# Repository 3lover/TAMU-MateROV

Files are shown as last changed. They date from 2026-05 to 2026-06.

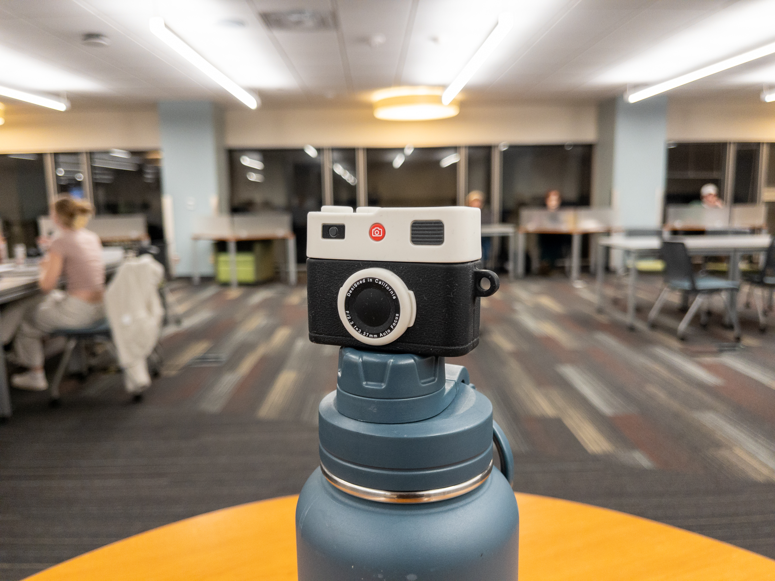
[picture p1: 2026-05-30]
25-26/01_Subteams/GNC/Photogrammetry Test Files/APC_0051.jpg

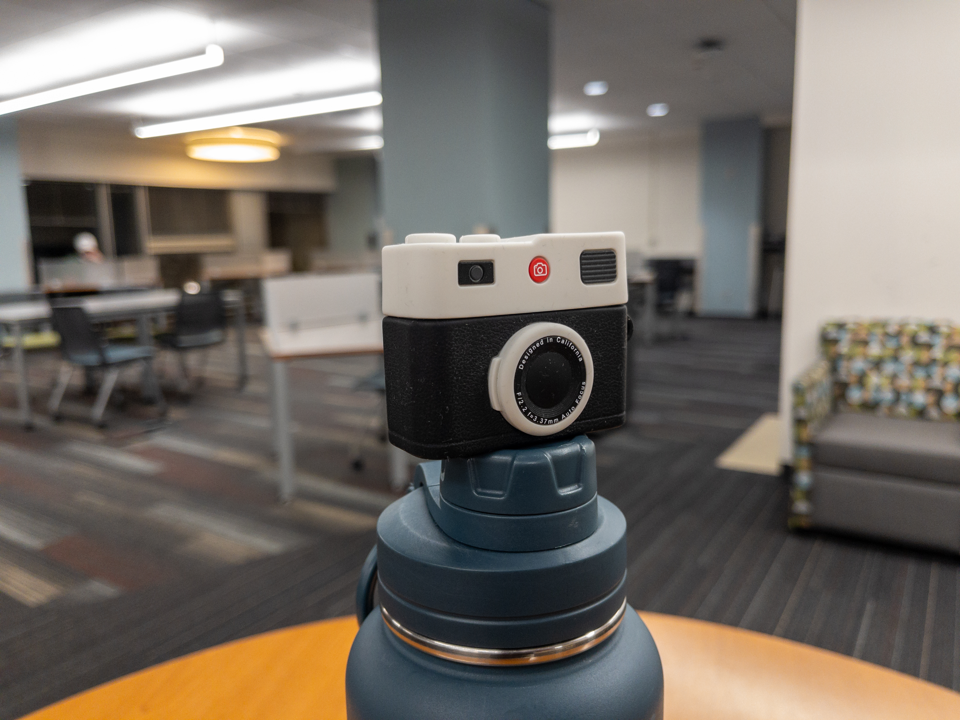
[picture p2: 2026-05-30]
25-26/01_Subteams/GNC/Photogrammetry Test Files/APC_0047.jpg

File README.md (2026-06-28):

# Team Oceanus — MATE ROV 🌊

Texas A&M underwater robotics team (ThinkTank) building an ROV and float for the
[MATE ROV Competition](https://materovcompetition.org/). This is our team
monorepo — design, code, and documentation, organized by subteam.

## The ROV at a glance

- **8-thruster, fully 6-DoF frame** — vectored (ArduSub `vectored_6dof`), with independent roll & pitch
- **Diamond Dynamics TD1.2** thrusters (4 horizontal + 4 vertical)
- **Navigator** flight controller on a **Raspberry Pi 5**, running **BlueOS + ArduSub**
- Piloted over **MAVLink** in QGroundControl; a companion **float** (vertical profiler) runs its own firmware

## Subteams

| Subteam | Focus |
|---|---|
| **GNC** — Guidance, Navigation & Control | Control software, ArduSub SITL simulation, photogrammetry |
| **EPS** — Electrical Power Supply | Power distribution, PCB design |
| **TMS** — Thermal Mechanisms & Structures | Chassis, frame, claw, and float CAD |
| **C&C** — Communication & Computing | ROV & float code, software architecture |
| **F&P** — Fluids & Propulsion | Propellers, fluid/structural analysis (CFD/FEA) |

Each subteam's plans and notes live under [`01_Subteams/`](01_Subteams/).

> **Note:** C&C and GNC are planned to merge into a single subteam.

## Repository layout

| Path | Contents |
|---|---|
| [`01_Subteams/`](01_Subteams/) | Active work, by subteam (**canonical**) |
| [`FloatCode/`](FloatCode/) | Float (vertical profiler) firmware |
| [`ROV CAD files/`](ROV%20CAD%20files/) | Mechanical CAD |
| [`WiringSchematics/`](WiringSchematics/) | Electrical wiring diagrams |
| [`Technical Data/`](Technical%20Data/) | Datasheets and specs |
| [`doc/`](doc/) | Documentation |
| `25-26/` | Previous-season archive (not active) |

## Software highlights

- **GNC SITL simulation** — full ArduSub 6-DoF sim of our ROV, for testing control before hardware: [`01_Subteams/GNC/SITL-Simulation`](01_Subteams/GNC/SITL-Simulation)
- **Photogrammetry Studio** — RTSP-to-3D scanning app (macOS): [latest release](https://github.com/akvaithi/MATE-ROV-Photogrammetry/releases/latest)

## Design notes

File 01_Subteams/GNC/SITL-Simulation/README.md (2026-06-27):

# GNC SITL Simulation — ArduSub 6-DoF

Software-In-The-Loop (SITL) environment for validating Team Oceanus' control
systems and **custom 6-DoF frame configuration** before they touch hardware.

This runs the **real ArduSub firmware** against a simulated vehicle, so the same
frame mixing, PID loops, depth/heading hold, and MAVLink commands you test here
behave identically on the **Navigator + Raspberry Pi 5 + BlueOS** stack
(per `GNC-ICD-01`). That's why SITL is the right tool — not a hand-rolled
physics sim, which wouldn't match the autopilot.

> Covers **Goal 1 (Configure & Simulate 6-DoF Vehicle)** and **Practice Project 2
> (MAVLink heartbeat + IMU read)**, and gives the servo/thruster work
> (**Goal 2**) a place to run before hardware is ready.

---

## Status: validated end-to-end ✅

Built and run on macOS (Apple Silicon) with **ArduSub V4.5.7**. The sim boots
into `Frame: VECTORED_6DOF`, telemetry streams, and all six degrees of freedom
exercise the expected thrusters:

| Command | horizontal 1-4 | vertical 5-8 |
|---|---|---|
| neutral | 1500 1500 1500 1500 | 1500 1500 1500 1500 |
| forward | 1250 1250 1750 1750 | 1500 1500 1500 1500 |
| lateral | 1750 1250 1750 1250 | 1500 1500 1500 1500 |
| heave | 1500 1500 1500 1500 | 1250 1250 1250 1250 |
| yaw | 1750 1250 1250 1750 | 1500 1500 1500 1500 |
| roll | 1500 1500 1500 1500 | 1750 1250 1750 1250 |
| pitch | 1500 1500 1500 1500 | 1250 1250 1750 1750 |

Independent **roll and pitch** (driven by the 4 vertical thrusters) confirm true
6-DoF — a 2-vertical-thruster frame could not do this.

---

## The 6-DoF decision (why `vectored_6dof`)

| Frame | Thrusters | Controllable DoF | ArduSub `FRAME_CONFIG` |
|---|---|---|---|
| `vectored` (BlueROV2) | 6 (4 vec + 2 vert) | 4 — surge, sway, heave, yaw | 1 |
| **`vectored_6dof` (BlueROV2 Heavy)** | **8 (4 vec + 4 vert)** | **6 — adds roll & pitch** | **2** |

True, independently-controllable 6-DoF needs the **4 vertical thrusters** — with
only 2 vertical thrusters you cannot actively control roll and pitch. The
**8-thruster `vectored_6dof`** frame is the team's **final design** (confirmed
June 2026; BOM = 4 CW + 4 CCW T200s, ICD wiring T1–T8). See
[../Frame-Config-Decision.md](../Frame-Config-Decision.md).

---

## Prerequisites

- **Docker Desktop** (macOS/Windows/Linux). This is the clean path on macOS,
  where native ArduPilot builds are painful.
- **QGroundControl** (for visual flight + PID tuning) — optional but recommended.
- **Python 3.10+** on your host for the scripts (`pip install -r scripts/requirements.txt`).

## Quick start

```bash
cd "01_Subteams/GNC/SITL-Simulation"
./run_sitl.sh            # first run builds the image (~20-40 min, ~6 GB), then launches
```

When it prints the MAVProxy banner, the sim is live:

| Connect | Endpoint | For |
|---|---|---|
| GNC scripts / pymavlink | `tcp:127.0.0.1:5780` | telemetry + commands |
| QGroundControl | `tcp:localhost:5781` | add **Application Settings → Comm Links → Add → TCP**, host `localhost`, port `5781` |

Then, in another terminal:

```bash
cd "01_Subteams/GNC/SITL-Simulation"
python3 -m venv .venv && source .venv/bin/activate
pip install -r scripts/requirements.txt

python3 scripts/sitl_check.py        # Project 2: heartbeat + live IMU / attitude / depth
python3 scripts/thruster_mixing.py   # drive each DoF, confirm 8-thruster frame mixing
```

Stop the sim with `Ctrl-C` in the `run_sitl.sh` terminal.

## Capturing & presenting results

No 3D viewer needed — record a run and turn it into one shareable figure:

```bash
# 1. start logging in one terminal (depth, attitude, position, power, thrusters)
python3 scripts/log_telemetry.py tcp:127.0.0.1:5780 run1.csv 10
# 2. fly the ROV (QGC joysticks, or thruster_mixing.py) — Ctrl-C the logger when done
# 3. render a dashboard PNG for the test report / presentation
python3 scripts/plot_telemetry.py run1.csv run1.png "Dive + Forward Test"
```

The dashboard shows the path travelled, depth profile, attitude, which thrusters
fired when, power draw, and speed — so testing reads as a picture, not numbers.

## Water-current testing (ConOps current compensation)

Stock ArduSub SITL is still water, so we patch the model (`apply_current_model.sh`,
baked into the image) so `SIM_WIND_SPD`/`SIM_WIND_DIR` act as a horizontal
**water current**. Set it live — no rebuild:

```bash
python3 scripts/inject_current.py 0.4 90   # 0.4 m/s toward east (090)
python3 scripts/inject_current.py 0        # back to still water
python3 scripts/inject_current.py demo     # drift at 0 / 0.5 / 1.0 m/s
```

Unpowered, the ROV drifts toward the current at the current speed — so you can
test drift detection and station-keeping / current-compensation control. See the
`current-drift_*` example in [sample-runs/](sample-runs/).

**Current compensation** — `station_keeping.py` is a PID position-hold (NED error
→ forward/lateral thrust, depth held by the autopilot) that cancels the drift:

```bash
python3 scripts/inject_current.py 0.4 90    # add a 0.4 m/s current
python3 scripts/station_keeping.py          # hold position against it
```

Tuned gains (Kp=440, Kd=230, Ki=210) hold to ~**0.01 m** steady-state against a
constant 0.4 m/s current (the integral term removes the proportional droop), and
**mean ~0.12 m** against a *random* current that changes every few seconds. See
the `current-compensation_*` and `variable-current_*` samples in
[sample-runs/](sample-runs/).

## Servo control architecture (Goal 2)

The manipulator servos are on PWM channels **14-16** (GNC-ICD-01). They default to
`SERVOn_FUNCTION = 0` (Disabled), which lets the GCS drive them directly with
`MAV_CMD_DO_SET_SERVO` — no reboot or reconfig:

```bash
python3 scripts/servo_control.py gripper open       # ch14 -> 1900
python3 scripts/servo_control.py 14 deg 90          # angle command
python3 scripts/servo_control.py 15 sweep           # exercise a channel
python3 scripts/servo_test.py tcp:127.0.0.1:5780 14 40   # latency + precision -> report
```

`servo_test.py` produces the **Goal 2 test report** (`sample-runs/servo-control_report.md`):
command-path latency **~10 ms** (mean) and **0 µs** command error in SITL.

> SITL models the command/firmware path, not mechanical servo travel or physical
> positional error — measure those on the bench and add to the latency above.

---

## What's in here

| File | Purpose |
|---|---|
| `Dockerfile` | Builds ArduSub SITL from source (firmware = ground truth) |
| `sim_entry.sh` | Container entrypoint: starts SITL + a MAVProxy hub (multi-client) |
| `docker-compose.yml` / `run_sitl.sh` | One-command build & launch |
| `apply_oceanus_model.sh` + [`OCEANUS-VEHICLE-MODEL.md`](OCEANUS-VEHICLE-MODEL.md) | Patches SITL physics to our ROV's mass/size/thrust (edit + rebuild to update) |
| `params/vectored_6dof.parm` | The custom-frame parameter set (also `param load`-able onto the real Navigator) |
| `scripts/sitl_check.py` | Project 2 — heartbeat + IMU/attitude/depth stream |
| `scripts/thruster_mixing.py` | Drive each DoF via RC override, read SERVO_OUTPUT_RAW |
| `scripts/log_telemetry.py` | Record depth/attitude/position/battery/thrusters to CSV for reports |
| `scripts/plot_telemetry.py` | Turn a logged CSV into a shareable dashboard PNG (no 3D sim needed) |
| `scripts/inject_current.py` | Add a water current (ConOps drift / current-compensation testing) |
| `scripts/station_keeping.py` | PID position-hold that counters the current (ConOps current compensation) |
| `scripts/servo_control.py` | Drive the manipulator servos (ch 14-16) via MAV_CMD_DO_SET_SERVO |
| `scripts/servo_test.py` | Servo latency + precision test → CSV, chart, report (Goal 2) |
| `apply_current_model.sh` | Build-time patch making SIM_WIND act as a water current |

---

## Custom ArduSub frame config — step by step (deliverable)

1. **Pick the frame.** 8-thruster Heavy geometry → `FRAME_CONFIG = 2` (`vectored_6dof`).
   In SITL this is selected by `sim_vehicle.py -f vectored_6dof` (already wired in `sim_entry.sh`).
2. **On hardware**, set the same in QGroundControl → **Vehicle Setup → Frame**, or
   load `params/vectored_6dof.parm` via **Parameters → Tools → Load from file**.
3. **Confirm the mixing** with `scripts/thruster_mixing.py`: each DoF should move
   the expected group of thrusters (horizontals for surge/sway/yaw, verticals for
   heave/roll/pitch). Cross-check against `GNC-ICD-01 Figure 4 (Thruster
   Configuration)` and the
   [ArduSub thruster setup guide](https://www.ardusub.com/quick-start/vehicle-frame.html).
   (Note: ArduSub's `MAV_CMD_DO_MOTOR_TEST` is unreliable in SITL — it times out —
   so we exercise the mix via RC override instead.)
4. **Tune** depth-hold / heading-hold (`PSC_POSZ_P`, `ATC_ANG_YAW_P`) in QGC
   against SITL, then carry the values to the Navigator.
5. **Non-standard geometry?** If the thruster angles/positions differ from
   BlueROV2 Heavy, a fully custom motor matrix means editing
   `AP_Motors6DOF::setup_motors()` and rebuilding (bump `FRAME_CONFIG` to its
   Custom slot). Open an issue and we'll branch the Dockerfile for it.

---

## Troubleshooting

- **Build fails on `install-prereqs`** — usually a transient apt mirror issue;
  re-run `./run_sitl.sh`. The build layer is cached up to that point.
- **`FRAME_CONFIG` not 2 after boot** — connect with QGC or MAVProxy and
  `param set FRAME_CONFIG 2`, then reboot the sim. Report it so we can pin the param file.
- **Scripts can't connect** — make sure `run_sitl.sh` printed the MAVProxy banner
  and ports 5780/5781 aren't taken (`lsof -i :5780`).
- **Different ArduSub version** — rebuild with another release:
  `docker compose build --build-arg ARDUSUB_REF=Sub-4.1`.

## References

- ArduSub SITL setup — https://www.ardusub.com/developers/sitl.html
- ArduSub frames / thrusters — https://www.ardusub.com/quick-start/vehicle-frame.html
- pymavlink + ArduSub examples — https://www.ardusub.com/developers/pymavlink.html
- MAVProxy — https://ardupilot.org/mavproxy/

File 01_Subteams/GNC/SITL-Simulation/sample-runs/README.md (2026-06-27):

# Sample SITL runs

Example telemetry from the same scripted maneuver (settle → dive → cruise → turn
→ forward → strafe → surface), captured with `scripts/log_telemetry.py` and
rendered with `scripts/plot_telemetry.py`.

| Run | Vehicle model | Dive (same command) |
|---|---|---|
| `bluerov2-baseline_*` | ArduPilot stock BlueROV2 (10.5 kg, T200-class 51.5 N) | ~5.8 m |
| `oceanus-td12_*` | Team Oceanus model: 22 kg + **Diamond Dynamics TD1.2** thrusters (24.5 N) — see [../OCEANUS-VEHICLE-MODEL.md](../OCEANUS-VEHICLE-MODEL.md) | ~3.5 m |
| `current-drift_*` | Oceanus model holding depth while a **0.6 m/s current** is switched on — drifts ~14 m east (ConOps current-compensation test) | n/a |
| `current-compensation_*` | `station_keeping.py` PID vs a **0.4 m/s current**: drifts ~3.9 m during a no-control phase, then recovers to within ~0.2 m and holds | n/a |
| `variable-current_*` | `station_keeping.py` (tuned) vs a **random current** that changes every ~3–4 s (13 changes): holds **mean 0.12 m / max 0.31 m**. `_response.png` overlays the disturbance and the position error | n/a |
| `servo-control*` | **Goal 2** servo test on ch 14: command-path latency ~10 ms mean, 0 µs precision error. `_report.md` is the test report, `.png` the latency/precision chart, `.csv` the raw data | n/a |

Same command, shallower dive: the Oceanus ROV is heavier **and** its TD1.2 thrusters
push less than half a T200, so it's a slower, gentler vehicle. Top speed in the
Oceanus run is ~0.7 m/s vs ~1.2 m/s on the baseline.

Each run has a `_dashboard.png` (shareable figure) and a `_telemetry.csv` (raw log).
The Oceanus model still uses **design-target/estimated** mass and dimensions
(only the thrusters are a confirmed real value) — regenerate once the ROV is weighed.

To make your own: see "Capturing & presenting results" in the [main README](../README.md).

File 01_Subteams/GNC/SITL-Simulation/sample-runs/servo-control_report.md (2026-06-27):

# Servo Control Architecture — Test Report

**Channel:** 14 (manipulator, per GNC-ICD-01)  ·  **Iterations:** 40  ·  **Env:** ArduSub SITL

## Response latency (MAV_CMD_DO_SET_SERVO → output register)
| metric | value |
|---|---|
| mean | 10.0 ms |
| p95  | 18.0 ms |
| max  | 27.8 ms |

Measured at 200 Hz SERVO_OUTPUT_RAW (±5 ms quantisation). This is the
MAVLink + firmware command latency, not mechanical servo travel.

## Command precision (commanded vs actual PWM)
| metric | value |
|---|---|
| max error | 0 µs |
| range tested | 1100–1900 µs |

The command path is exact in SITL (pass-through), so precision here validates
PWM resolution, not mechanical positioning.

## On hardware (to be measured on the bench)
- Mechanical travel time per degree (add to the latency above).
- Physical positional accuracy / repeatability of the servo.
- Holding torque under load.

Artifacts: `servo-control.csv`, `servo-control.png`

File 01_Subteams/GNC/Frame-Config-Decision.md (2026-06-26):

# Frame Config — Decision Record

**Decision:** The ROV uses **8 thrusters** in a **vectored 6-DoF** layout
(BlueROV2 "Heavy" style). In ArduSub this is **`FRAME_CONFIG = 2`
(`vectored_6dof`)**. *Final as of June 2026.*

## Why / evidence
| Source | Evidence |
|---|---|
| GNC-ICD-01, Fig. 4 (wiring) | T1–T8 → ESC 1–8 → PWM channels 1–8; 3 servos on channels 14–16 |
| Thrusters | 4 CW + 4 CCW **Diamond Dynamics TD1.2** = 8 (torque-balanced pairs; ~2.5 kgf max each) |
| CAD | `Horizontal Mount` + `Vertical Mount` parts; `Thruster Configuration Assembly.SLDASM` |
| Hardware | Navigator flight controller + Pi 5 + BlueOS + ArduSub |

8 thrusters give true 6-DoF: 4 horizontal (surge / sway / yaw) + 4 vertical
(heave / **roll / pitch**). A 6-thruster frame (2 vertical) could not control
roll and pitch — that's why 8 is required.

## Resolved conflict
Earlier design docs disagreed on count:
- `F&P/.../Thrusters - Number...` leaned toward **4** thrusters (no pitch).
- `Research Notes/GNC/ROV Software & Hardware Architecture...` cited a **4**-thruster baseline.
- BOM + ICD wiring specify **8**.

**8 is final.** The blank "6 positions" in the spec-sheet *template* is just an
unfilled template, not the design.

## Still to verify in CAD (does not affect the sim)
`vectored_6dof` assumes the 4 horizontal thrusters are mounted **~45° in the
corners**. Confirm in `Thruster Configuration Assembly.SLDASM` (top-down):
- Horizontals **45°-vectored** → `vectored_6dof` is exact, no extra work.
- Horizontals **straight** → custom motor matrix needed (recompile ArduSub).

Validated in SITL — see [SITL-Simulation/](SITL-Simulation/).

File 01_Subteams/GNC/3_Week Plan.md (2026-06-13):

# GNC Project Plan

## Objective

Finalize GNC software configurations, validate remaining control systems in simulation, validate servo control architecture, and refine the photogrammetry pipeline for future hardware integration.

---

## Goals Overview

| Goal | Measurables | Deliverables |
|---|---|---|
| **Configure & simulate 6-DoF vehicle** | Successful loading of custom 6-DoF frame config into ArduSub/BlueOS; successful execution of control algorithms in SITL | Custom frame configuration file; validated simulation environment; updated control architecture documentation |
| **Validate servo control architecture** | Successful actuation of test servos via BlueOS/MAVLink; minimal latency and precise positional control achieved | Code repository with servo control scripts; test report documenting response times and precision metrics |
| **Refine photogrammetry pipeline** | Continuous processing of RTSP video stream into 3D models with minimal error and dropped frames | Updated Python application code; documentation of RTSP-to-3D pipeline and performance metrics |

---

## Software & Tools

| Software/Tool | Purpose | Members | Resources/Links |
|---|---|---|---|
| BlueOS | Core ROV operating system and communication | All GNC members | [BlueOS Documentation](https://docs.bluerobotics.com/ardusub-zola/software/onboard/BlueOS/) |
| Python | Custom application development (photogrammetry, control scripts) | All GNC members | [Python.org](https://www.python.org) |
| MAVLink / pymavlink | Communication protocol between GNC software and hardware | All GNC members | [MAVLink Developer Guide](https://mavlink.io/en/) |
| ArduSub (SITL) | Software-in-the-loop simulation for testing control algorithms and custom frame configurations | All GNC members | [ArduSub SITL Guide](https://ardusub.com/developers/sitl.html) |
| GitHub | Version control and task management | All GNC members | [TAMU-MateROV Repo](https://github.com/3lover/TAMU-MateROV) |

---

## Training Plan

**Custom frame configuration in ArduSub**
- Review ArduSub documentation on creating and compiling custom motor matrices for non-standard frame geometries

**BlueOS & MAVLink fundamentals**
- All new/junior members complete a tutorial on sending basic MAVLink commands via Python to a simulated BlueOS instance

**Photogrammetry pipeline review**
- Async or recorded walkthrough covering the custom Python app structure and the RTSP video ingestion process

---

## Practice Projects

- **Project 1 — Simulation:** Create a basic alternative motor matrix (e.g., simple 4-thruster setup) and load it into SITL to understand the configuration pipeline
- **Project 2 — MAVLink:** Write a Python script to send a basic heartbeat message via MAVLink and read simulated IMU data from the SITL environment
- **Project 3 — Photogrammetry:** Modify the existing photogrammetry app to include error logging if the RTSP stream drops or experiences high latency

---

## Documentation

- **Summer progress tracker** — weekly updates on individual task progress
- **Custom ArduSub config guide** — step-by-step instructions for defining and loading the custom motor matrix into ArduSub
- **Photogrammetry app** — detailed usage instructions and architecture overview: [MATE-ROV-Photogrammetry](https://github.com/akvaithi/MATE-ROV-Photogrammetry)

---

## Timeline

All tasks are assigned and tracked via [GitHub Issues](https://github.com/3lover/TAMU-MateROV).

| Week | Tasks |
|---|---|
| **Week 1** | Set up SITL environments; begin 6-DoF frame configuration in ArduSub; define servo testing protocols |
| **Week 2** | Load 6-DoF config into SITL and begin simulated flights; execute servo testing (async) |
| **Week 3** | Finalize photogrammetry app refinements; compile servo test reports; update GNC documentation with 6-DoF simulation results |

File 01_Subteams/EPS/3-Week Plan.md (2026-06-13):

# EPS Project Plan

## Goals Overview

| Goal | Measurables | Deliverables |
|---|---|---|
| **Onboard team to EPS** | All members demonstrate understanding of EPS purpose and responsibilities | Word doc with overview of tasks to accomplish and open questions |
| **Understand the previous PCB** | All members understand PCBs in general and how the MATE ROV PCB is used | Readable doc describing how the PCB works + short usage guide for future reference |
| **Learn power/system requirements** | All members understand how power is used in the ROV and float | Doc explaining how EPS used power requirements last year and how they created component restrictions |

---

## Team Members

| Name | Skills | Training Focus |
|---|---|---|
| Christopher Gibbs | Basic circuits | TBD |
| Dhruv Murthy | — | TBD |
| Nate Waguespack | — | TBD |

---

## Software & Tools

| Software/Tool | Purpose | Members | Resources/Links |
|---|---|---|---|
| LTspice | Circuit design and testing; understanding voltage and current | All | [LTspice Simulator](https://www.analog.com/en/resources/design-tools-and-calculators/ltspice-simulator.html) |
| KiCAD | Reading and understanding the past PCB (full proficiency not required) | All | [KiCAD Download](https://www.kicad.org/download/) |

---

## Training Plan

**LTspice**
- Learn how to find power in simple circuits
- Build a circuit with resistors in series and parallel; calculate power absorbed/dissipated

**KiCAD**
- Learn to read and navigate PCBs in the program
- Create a simple PCB that would power an LED

---

## Documentation

All documents should be linked and maintained in the [MATE ROV GitHub](https://github.com/3lover/TAMU-MateROV).

- **Google Doc — EPS Overview:** Document what the team learned about EPS and define responsibilities for the year
- **Google Drawing — PCB Overview:** Diagram the PCB design, highlight different current paths, and explain how each can be used
- **Google Sheet — Past Power Requirements Overview:** Reference last year's power requirements doc and note how different components created power restrictions

---

## Timeline

| Deadline | Task |
|---|---|
| **May 24, 2026** | EPS overview document completed |
| **May 31, 2026** | PCB overview document completed |
| **June 7, 2026** | Past power requirements overview completed |

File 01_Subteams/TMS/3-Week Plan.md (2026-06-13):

# TMS Project Plan

## Goals Overview

| Goal | Measurables | Deliverables |
|---|---|---|
| **Finish CAD for Chassis** | Completion of frame; plan for 3D printing so striations are strong and won't result in cracking; verify PLA is insoluble; more possible fluid tests in water | Completed assembly in GitHub; bill and plan for filament; assembly spliced and ready for 3D printing; tapered washers CADed |
| **Float** | Collaboration and deliberate new design options for float; create solution for internal ballast system; design pressure release | New design incorporating internal ballast system (needs F&P collaboration); fully designed pressure release |
| **Claw Improvements** | Complete deliberation about claw design and whether changes or improvements are wanted | Final idea or improvement implemented |

---

## Team Members

| Name | Skills | Training Focus |
|---|---|---|
| Alexandria Llavona | SolidWorks, Manufacturing | Leading sub-team to create a functional ROV |
| Matthew | CAD and prototyping | TBD |
| Ryann | CAD and stress work | TBD (CAD, stress testing) |
| Elif | CAD and manufacturing | TBD |

---

## Software & Tools

| Software/Tool | Purpose | Members | Resources/Links |
|---|---|---|---|
| SolidWorks | 3D Modeling | All Members | — |
| Fab Lab / RPS / FEDC | Constructing and printing ROV | TBD | — |

---

## Training Plan

> **Action Required:** Get your [Red Badge](https://fedc.tamu.edu/) — sign up on the FEDC website as soon as possible!

Team members will use the Red Badge to access fabrication equipment, get familiar with SolidWorks, and build skills in CADing, printing, and assembling the final product.

---

## Documentation: Known Issues & Fixes

### Chassis

- **CAD:** Thicken lower and upper enclosure so heated inserts don't pop through
- **Striation Cracks**
  - *Long-term fix:* Print chassis parts long-ways (cracks form along striations)
  - *Short-term fix:* Heat gun set to 305°C, heat until plastic melts together
- Ballast system is currently external — needs to be internal
- Limit holes on the float; use multiple waterproofing methods

### Claw Parts

- Wrist joint is good; holes in claw joint need remodeling (too close to edge)
- Thicken middle section due to heated inserts sticking through
- **Use heated inserts** — much better than tapping
- If a heated insert starts to twist:
  1. Leave the target screw in the hole while inserting
  2. If stripped: heat soldering iron, remove it, use a 3D pin to fill the hole, redrill, and place a new heated insert
- If a screw won't pass through the insert, there is likely plastic in the threads:
  - Pick out the threads (time-consuming), or repeat the insert replacement process
- Double the waterproofing on the float (e.g., o-rings + epoxy coating)

### Brackets

- Need to be bigger — current brackets are too thin and flex too easily
- Any metal on the claw should use the thicker metal stock purchased this semester
- **Hole alignment issues:** Drill bracket holes larger if needed, but best practice is to drill all holes first, place heated inserts, confirm screws seat, then measure distances with calipers

### General

- Improve naming conventions
- Use zip files for sharing assemblies

---

## Timeline

### Summer — 3-Week Sprint

| Date | Task |
|---|---|
| June 8–10 | Requirements complete |
| Week 1–2 | Get changes made to the chassis; deliberate float changes (integrate internal ballast); save all new chassis versions to [GitHub](https://github.com/3lover/TAMU-MateROV) |
| Week 2–3 | Discuss and implement claw modifications; complete Red Badge training |

### Fall Semester

- After first PDR: begin 3D printing PLA chassis parts before the print rush
- Print new brackets
- Assemble chassis and thrusters as early as possible → hand off to GNC for code testing
- Place GNC sensors during assembly
- Once competition tasks release: begin printing claw parts (may overlap with finals — okay to push to spring)

### Spring Semester

- Assemble claw with ROV
- Test and verify; if no issues, hand off to GNC for code integration

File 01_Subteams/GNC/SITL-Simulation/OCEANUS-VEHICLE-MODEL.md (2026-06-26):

# Oceanus Vehicle Model (SITL physics)

By default, ArduSub SITL flies ArduPilot's generic **BlueROV2** reference vehicle
(hardcoded in `libraries/SITL/SIM_Submarine.h`). We patch it with Team Oceanus'
numbers so the simulated **dynamics approximate our ROV**, via
[`apply_oceanus_model.sh`](apply_oceanus_model.sh) (run at image-build time).

> ⚠️ The control firmware (frame mixing, PID, MAVLink) is always real. This patch
> only affects the *physics body* — how fast it accelerates, glides, and turns.

## Values applied & where they came from

| Parameter | Value | Source | Confidence |
|---|---|---|---|
| Thrusters | 8 (vectored_6dof) | 4 CW + 4 CCW Diamond Dynamics TD1.2, GNC-ICD-01 wiring | **real** |
| Thrust / thruster | 24.5 N | Diamond Dynamics **TD1.2** max forward ~2.5 kgf (range 1.2–2.5 kgf; Technical Report + manufacturer) | **real** |
| Mass (`weight`) | 22.0 kg | design targets: <35 hard / <25 / <18 (TMS reqs, F&P "25 kg max") | **target — not measured** |
| Length | 0.60 m | "<1 m any dimension" req; 400 mm enclosure/chassis | estimate |
| Width | 0.50 m | same | estimate |
| Height | 0.35 m | same | estimate |
| Thruster mount radius | 0.28 m | frame scale | estimate |
| Equivalent sphere radius | 0.25 m | drag/inertia scale | estimate |
| Buoyancy | ~neutral (`SIM_BUOYANCY≈1`) | req: avg density = water (1 kg/L) | target |
| Drag coefficients | ArduPilot defaults [1.4, 1.8, 2.0] | **no measured hydrodynamics in repo** | unchanged |

## What's NOT in the repo (so these are estimates)
The 25-26 spec sheet is a blank template — there is **no measured assembled-ROV
mass or overall dimension** anywhere in the docs, only requirements/limits and
component data. **Update the values when the ROV is built and weighed.**

## How to update
1. Edit the variables at the top of [`apply_oceanus_model.sh`](apply_oceanus_model.sh).
2. Rebuild: `docker compose build` (recompiles SITL with the new model).
3. Restart: `./run_sitl.sh`.

Buoyancy alone is a live parameter — set `SIM_BUOYANCY` in QGroundControl/MAVProxy
without rebuilding.

## Caveats
- Mass is modelled twice in ArduPilot (`weight` for linear accel, a sphere-derived
  `mass` for rotational inertia) — an upstream approximation, not ours.
- Steady descent/cruise speed is **drag-limited** (≈ thrust vs drag), so it's
  largely mass-independent; mass shows up in acceleration transients and turn rate.
- Drag is a sphere approximation — no tether drag, vortices, or per-axis added mass.

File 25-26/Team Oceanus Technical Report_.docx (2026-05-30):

# ThinkTank Oceanus

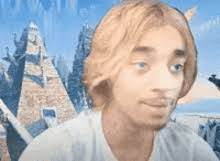
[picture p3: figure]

[Insert image of ROV here]

*I will probably design a cool cover page so do not mind this ugly cover! -Emily BWM

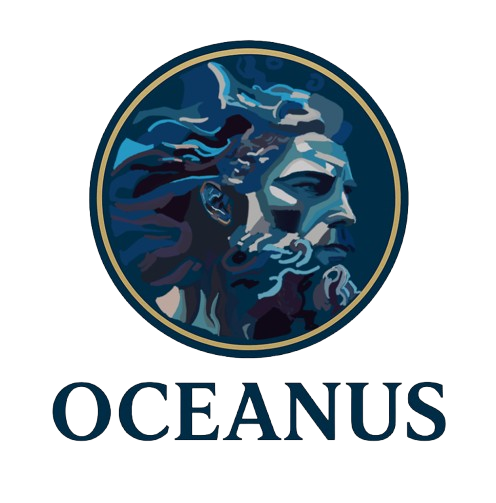
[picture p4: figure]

# Content

Abstract 3

Team Structure & Management 4

Systems of Engineering 5

TMS 6

EPS 6

F&P 6

GNC 7

C&C 7

System Integration Diagram (SID) 7

Safety 7

Testing 8

Accounting 8

# Abstract

Team Oceanus is an underwater robotics team based in College Station, Texas, USA. The team is part of TAMU ThinkTank within the AERO Department, an engineering organization for freshman and sophomore students that prioritizes strong teamwork, well-roundedness, passion, and the application of the fundamentals of systems of engineering.

This is Team Oceanus’ first year participating in this competition. Throughout the year, the team has conducted intensive research and worked hard toward the creation of an underwater ROV. Their mission is to support scientific research, environmental monitoring, and offshore energy infrastructure operations through the design and operation of a highly capable underwater ROV. This system emphasizes precise navigation, controlled manipulation, dynamic stability, and structural robustness, while complying with all electrical, mechanical, and safety requirements established by MATE.

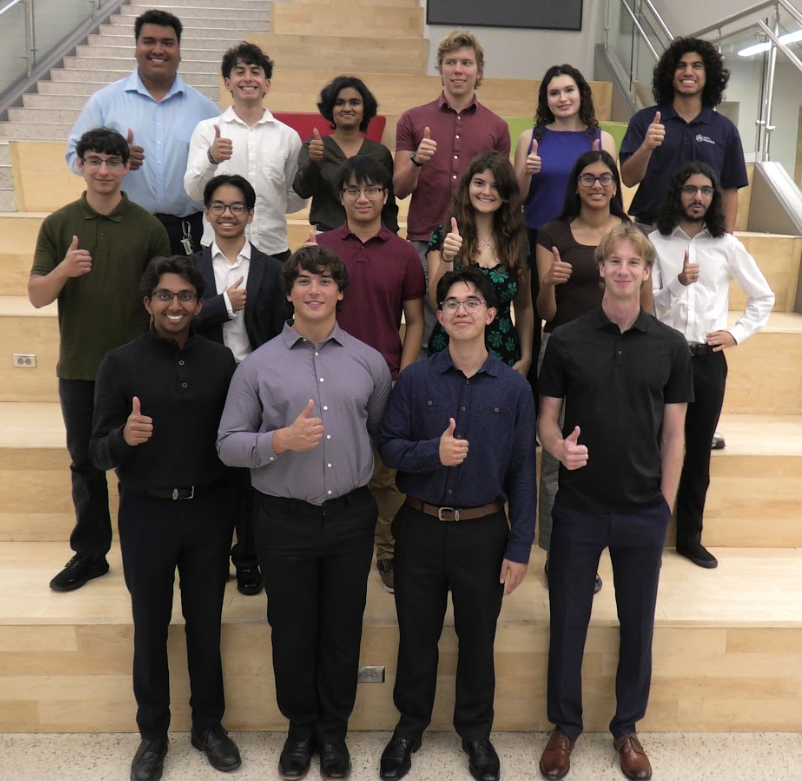
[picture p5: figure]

Figure 1. Group Photo of Team Oceanus

# Team Structure & Management

Team Oceanus is divided into five subteams and is led by two team leads, who work under the supervision of the Program Manager, an officer of the ThinkTank organization. Each subteam focuses on a specific aspect of the ROV's design, as described below.

- Thermal, Mechanisms, and Structures (TMS)

Focuses on the mechanical and structural design of the ROV, including the frame, material selection, sealing, and overall durability to ensure reliable underwater performance.

- Fluids and Propulsion (F&P)

Responsible for the propulsion system and hydrodynamic performance of the vehicle, working to improve efficiency, thrust, and maneuverability.

- Electrical and Power Systems (EPS)

Manages the distribution and regulation of electrical power, ensuring all subsystems receive consistent and safe power during operation.

- Guidance, Navigation, and Control (GNC)

Handles the movement and stability of the ROV, integrating sensor data and control logic to achieve precise navigation and positioning.

- Computation and Communications (C&C)

Develops the software and communication systems, enabling data transfer, control of the ROV, and coordination between all subsystems.

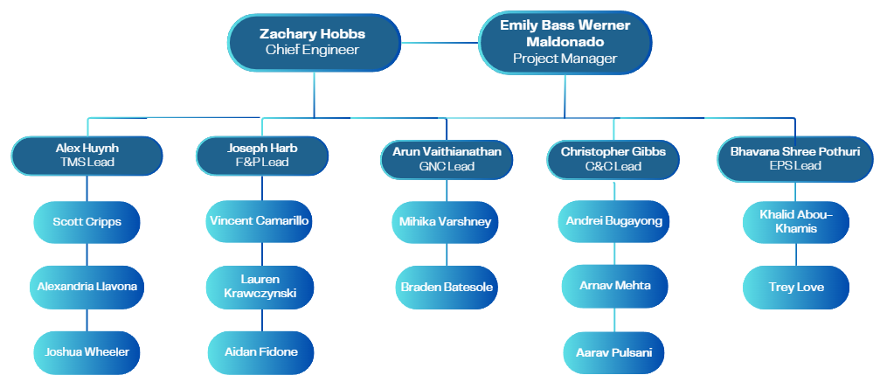
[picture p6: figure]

Figure 2. Team Structure of Oceanus

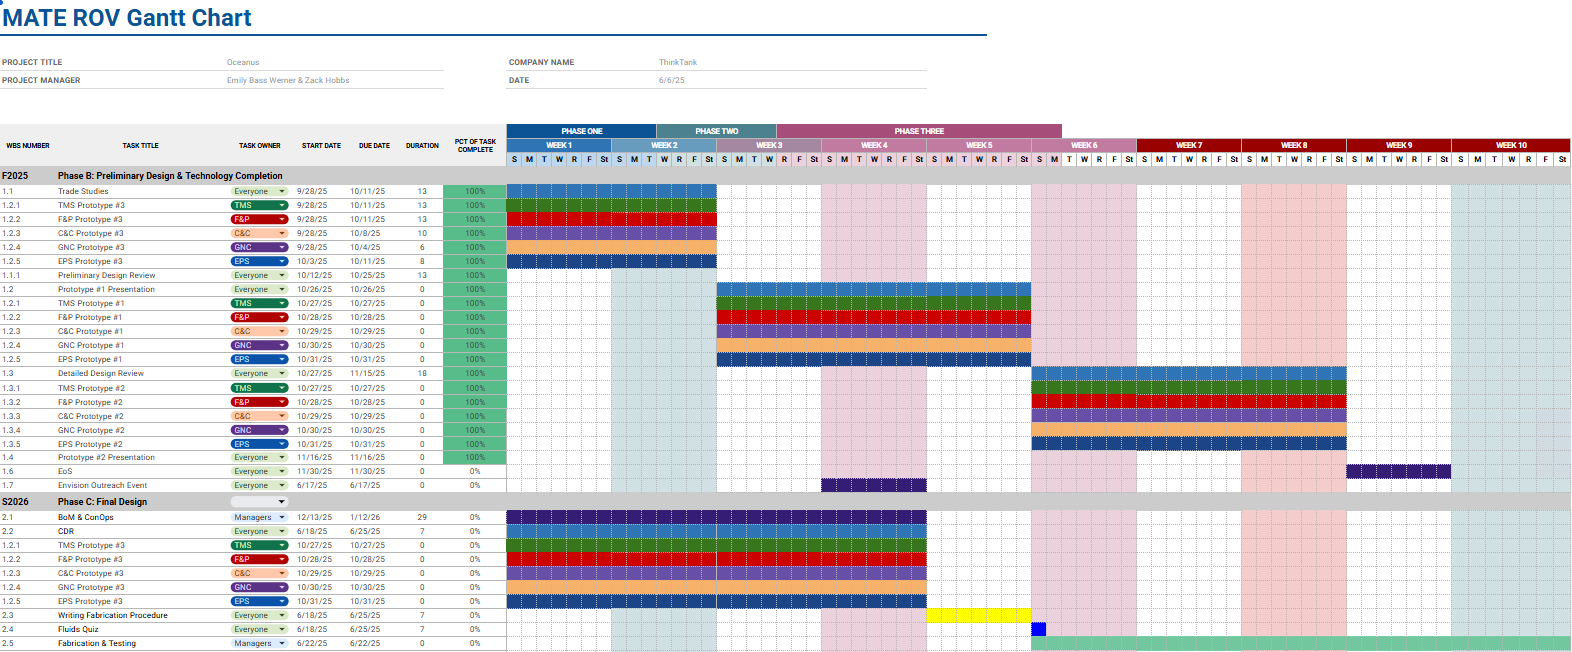
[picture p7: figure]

Figure 3. Timeline of Oceanus

RPS -> 3D printing, waterjetting

FEDC -> heated inserts, assembling ROV

Testing -> OTRC, FEDC

## Systems of Engineering

Effective procedures to minimize risk, ensure consistent documentation and validation and verification of our project, Team Oceanus has applied the Systems engineering through the use of a Risk Verification Matrix (RVM) in order to identify the Mission statement, mission objectives, needs and requirements for the MATE ROV 2026 Competition. The team held Preliminary Design Reviews (PDRs) and Critical Design Reviews (CDR) to present their CONOPS, RVM, and trade studies to internal and external reviewers that could provide useful feedback to ensure progress and good engineering practices.

This system allows the team to have efficient communication and constant checking of everybody's work to prevent misunderstandings and incompatibility across subteam’s solutions to their requirements.

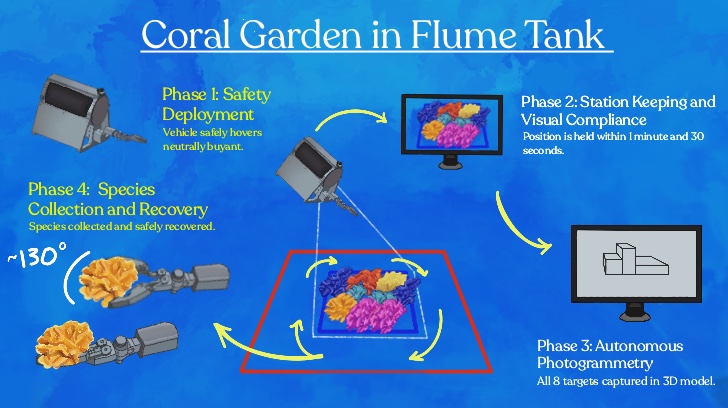
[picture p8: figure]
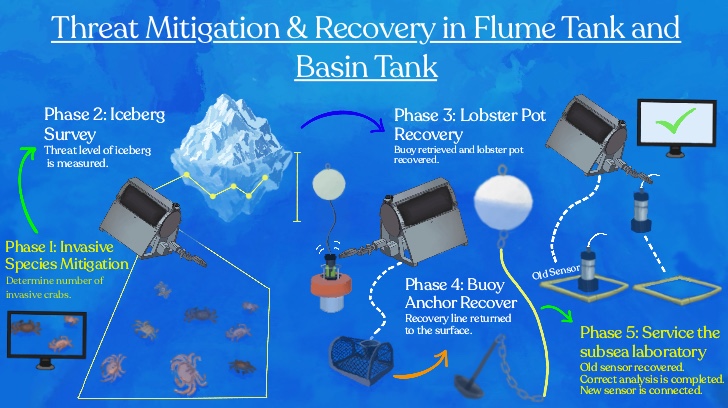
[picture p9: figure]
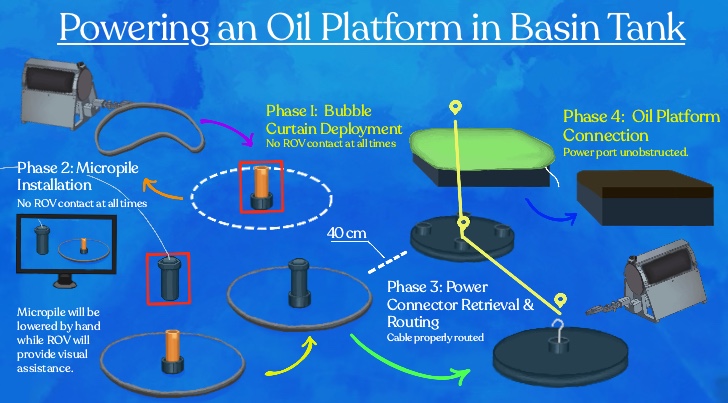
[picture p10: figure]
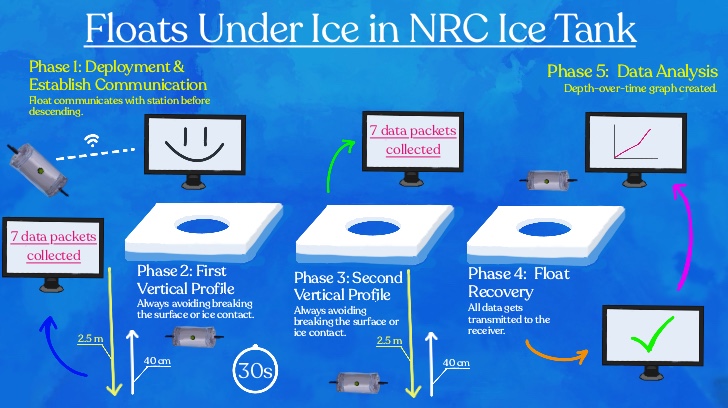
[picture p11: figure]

Figure 4. CONOPS for Task 1, Task 2, Task 3, & Task 4 from MATE ROV 2026

# TMS

Vehicle Structure:

Oceanus’s ROV prioritized ease of manufacturing, repairability, and low cost.

Rubric:

Timeline:
-Brainstorming/Reading Other Technical Reports

-Needs Requirements Goals

-Trade Studies

- Materials (Alex H)
- Waterproofing (Josh)
- Motors (Alex L)
- Thermal (Scott)
- Fasteners/Bolts (Scott)

- CAD

- Mechanical Arm (Alex L)
- Chassis (Alex L/Josh)
- Float (Scott)

-Prototyping

- Software Choices (?)
  - OrcaSlicer

[Explain that Orca slicer is required to use for RPS k1 3D printers along with the RPS presents, BTW YOU DO NOT NEED TO EXPLAIN WHAT RPS IS, THAT WAS SOMETHING THAT WAS EXPLAINED UNDER PROJECT MANAGEMENT, OR AT LEAST IT WILL BE]

    - Infill

[Explain that 50% infill is the selected infill due to the limitations of PETG, a very dense material can be very difficult to 3D print due to our cost and other limitations provided by the RPS. It was advice that 50% would be enough to withstand around 20 N of force]

    - Printing Speed

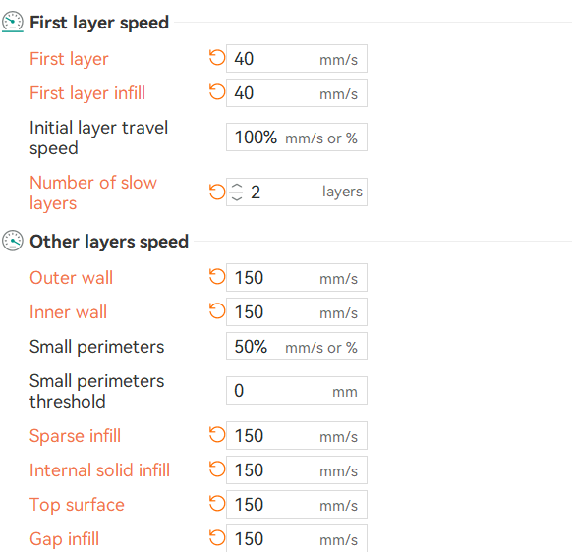
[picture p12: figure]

[Explain that lower speed is required due to PETG properties for a better visual quality but also structural efficiency!]

    - Cleaning Procedures?

[Explain that due to PETG properties, it has trouble sticking to the 3D printing bed. For this reason, it is necessary to prevent any oils and other barriers to stay within the bed through cleaning it with soap and then using then IPA before starting to 3D print]

- Chassis (Alex H/Alex L/Josh)
  - Overall Chassis design choices
    - The chassis design is configured to have eight thrusters, two on each side plate, and four underneath the electronics enclosure mounted to a baseplate. Three rings were utilized to create an exoskeleton-like design. Each ring is split into a top and bottom half in order to encapsulate the aluminum tube, redistributing forces towards the center of the ROV to provide strain relief. These rings are composed of semi circles fastened together at tabs. This three ring system also allows for ease of access to either side of the aluminum tubing.
  - Sideplates
    - Heated Inserts
    - The side plates are slanted, creating a trapezoidal interface on the front and back profiles of the ROV. Each sideplate has two holes to allow the baseplate thrusters to operate without obstruction or increased drag.
  - Brackets, aluminum,
  - Electronics Enclosure
    - Electronics Enclosure Plate
    - 400 mm length aluminum enclosure rated for 200 m. 100 mm ID
  - Mechanical Arm
    - Kdjdkdj
- Float (Scott/Alex H)
  - Electronics Enclosure
    - Modified cast acrylic enclosure rated for 140 m. 100 mm ID 200mm length.
    - Holes for sensors, ballast, recovery feature, and the pressure release stopper.
  - Water proofing
    - Wires are held in place through the end cap with Loctite marine epoxy on the inside face and polyurethane potting on the outside faces. Sensors use polyurethane potting on the outside faces as well, with thread sealant on the threads.
    - Talk about testing data.
  - Thermals
    - 1mm thermal insulation foam for -2 °C environment. 5 W silicon heating pad (insert graph)
    - Thermistors for temperature monitoring. Talk about how simulation data is supported by testing data. 9 C internal temperature.
  - Buoyancy
    - Zinc weight allows for low center mass and buoyancy adjustability (drill holes to counteract added weight). The system is neutrally buoyant. 1.4 kg.

-Other Documentation

- Mass Budget (Alex H)

# X.0 Electrical and Power Systems

## X.1 Power Architecture and Distribution Design

The ROV electrical system is centered around a custom Control PCB that distributes power after external voltage conversion from 48V to 12V and 5V. High-power DC-DC converters were intentionally kept off-board to reduce thermal loading, simplify PCB design, and improve reliability. Power is routed from these converters using Wago connectors, wiring, and pre-manufactured distribution blocks, allowing the PCB to focus on stable routing and filtering. The Control PCB utilizes wide copper pours and a centralized power bus to support high current loads while minimizing voltage drop.

The Float electrical system is built around a dedicated Float PCB that distributes regulated low-voltage power to control electronics. Operating at lower current levels, the board is optimized for clean power delivery and includes decoupling capacitors, bulk filtering, and a USB-C interface for onboard computing systems.

## X.2 Electrical Integration and System Architecture

The Control PCB serves as the central node for power distribution within the ROV, integrating all the subsystems. High-current paths are routed through wide copper regions, while a continuous ground plane provides low-impedance return paths and reduces electrical noise. Externalizing power conversion allows for modularity and improved system scalability.

The Float PCB functions as a low-power control hub, distributing regulated voltage to onboard electronics while maintaining separation between power and signal paths. This separation between high-current and low-power systems reduces interference and improves overall system stability.

## X.3 Power Stability and Noise Mitigation

The primary challenge in the ROV system was managing high current loads while maintaining voltage stability. This was addressed through centralized routing on the Control PCB and the implementation of a parallel capacitor bank to stabilize voltage during transient load conditions. Wide copper traces reduce resistive losses, while modular connectors simplify wiring and improve fault isolation.

For the Float system, stable and noise-free power delivery was critical. This was achieved through localized decoupling capacitors, short power paths, and physical separation from high-current components. These design choices minimize voltage ripple and ensure reliable operation of sensitive control systems.

## X.4 Component Selection and Implementation

The ROV system uses external DC-DC converters, Wago connectors, and distribution blocks selected for high current capability and ease of integration. This modular approach improves maintainability and allows rapid system modifications during testing.

The Float system uses capacitors, connectors, and a USB-C interface to support low-power electronics, which are organized in a compact layout.

## X.5 Cost-Constrained Design Decisions

High-cost integrated power systems were avoided in favor of a custom PCB combined with off-the-shelf components. External DC-DC converters were selected over PCB-integrated solutions.

Wago connectors and pre-manufactured distribution blocks were chosen instead of custom high-current PCB connectors to reduce complexity and cost. For the Float system, standard low-cost components were used to maintain functionality while minimizing expenses.

# F&P

- Ballast system and buoyancy
  - The ballast system is designed to achieve neutral buoyancy for the ~10 kg float, requiring approximately 10 L of displacement. A 6 L piston-based ballast chamber (160 mm diameter × 300 mm height) provides active buoyancy control by intaking and expelling water from an IV bladder, while the remaining 4 L is supplied by naturally buoyant materials such as foam. Fluid transfer is handled by a Kamoer KPHM600 peristaltic pump (Model 10017), selected for its compact size and reliable operation. The pump provides a flow rate of ≥600 mL/min at a rated power of 12 W and operates on 24 V DC. It utilizes BPT tubing for chemical resistance and durability, with noise levels below 65 dB and a motor lifespan of up to 2000 hours. An approximate 1.5:1 gear ratio may be used to balance force and efficiency. This system enables controlled, repeatable buoyancy adjustment while remaining within power and space constraints.
- Thruster choice and configuration
  - OCEANUS employs an 8 thruster configuration, allowing for 6 degrees of freedom to maximize mobility. The DIAMONDDYNAMICS thrusters provide 1.2-2.5 kg of thrust per unit at a rated power of 60W-312W. This provides sufficient thrust for multidirectional movement. The team anticipated the ROV to be prone to rotational instability due to the large surface area of the resistance and printability on the team’s FDM hardware made it a sound alternative. The mesh geometry was designed to satisfy IP-20 ingress protection requirements, with all apertures held to a maximum of 12.5 mm and axial clearances at the front and rear faces limited to 2 mm. This ensures that no solid probe, and critically no finger, can contact the rotating propeller. PETG’s layer adhesion properties at the design wall thickness were sufficient to maintain these tight tolerances post-print, and both materials are chemically compatible in chlorinated water with no galvanic interaction at their interface.

# GNC

- System Architecture and Hardware Design
  - The GNC architecture operates on a distributed control system connected via Ethernet, enabling real-time control, sensor fusion, and hardware abstraction. The core processing is handled by a Raspberry Pi 5 with 8GB RAM, which features a 2.4GHz quad-core Arm Cortex-A76. The team opted for the higher RAM version to ensure our camera feed was smooth.
  - The Pi 5 interfaces with the Blue Robotics Navigator Flight Controller (NAV) using the onboard GPIO pins. The NAV provides the necessary sensory and control hardware, including a 6-axis Inertial Measurement Unit (IMU), and 16 servo PWM channel outputs for thruster interfacing.
- Control System and Software Implementation
  - Operating System: The Pi 5 runs BlueOS, a Linux distro designed specifically for ROV operation. BlueOS has built-in support for USB camera feeds, IMU support via ArduSub firmware, and QGroundControl (detailed in C&C).
  - Navigation and State Estimation: Navigation algorithms continuously poll the IMU for depth, location, and velocity. Depth is calculated using raw sensor outputs modified by a calibration constant. Heading and position are updated at regular intervals (e.g., integrating turn rate and speed using 0.02 time steps) and mapped to Cartesian coordinates utilizing sine and cosine trigonometric functions.
  - Guidance and Proportional Control: The control loop utilizes tuned proportional constants to maintain stability, specifically kp_Yaw = 0.5 and kp_Depth = 1.2. The guidance logic includes strict parameters, such as a maximum depth threshold (e.g., 4 meters), which automatically alerts the control code to increase thruster values to prevent
  - Thrust Allocation: The ROV achieves 5 Degrees of Freedom (DOF). The control software maps joystick vector inputs into calculated PWM signals sent to the thrusters. The thrust allocation model mathematically resolves these vectors into forces to enable precise translational and rotational maneuvers.
- Sensor Integration and Mission Capabilities
  - Vision Systems: The ROV operates a dual camera system running through BlueOS: a Brio 1080p webcam (30 fps) for navigational pilot feed, and an ArduCam 4K camera (15 fps) for specialized vision tasks.
  - A dual camera system was chosen such that the ROV’s vision could include both a detailed and steady general cam.
  - Video is streamed over UDP to minimize latency. The Raspberry Pi handles transcoding the video stream to enable H.264 live video stream within QGroundControl.
  - Coral Garden Photogrammetry (Task 1): For the creation of the 3D coral model, GNC software triggers a high shutter speed mode in the 4K ArduCam to ensure frames are captured clearly and then are sent to the control station for processing (detailed in C&C).
  - Iceberg Profiling (Task 2): To calculate the threat level of the iceberg, the ROV synchronizes high-resolution depth readings with IMU heading vectors to map the keel geometry. Furthermore, a multi-point hover script executes distinct hold-position commands at five intervals, allowing stable image recognition bounding boxes to identify invasive green crabs.
  - Autonomous Float: The deployable Float utilizes its own microcontroller-driven buoyancy logic to perform vertical profiling. An integrated ultrasonic sensor maintains a safe standoff distance to avoid ice collisions, while a surface-detection trigger automatically initiates a Bluetooth data telemetry dump upon emerging.
- Testing, Troubleshooting, and Failsafes
  - Testing Methodology: The GNC system was subjected to rigorous "360 Tests" to evaluate rotational motion capabilities and verify that camera connections remained secure under physical stress. "Precision Tests" measured the ROV's accuracy in holding specific coordinates, while speed testing ensured the system could maintain clear image feeds and physical integrity under various thruster loads.
  - Software Failsafes: To combat unexpected hardware or communication failures, automated recovery protocols were coded into the system. If a camera disconnects, BlueOS attempts an automatic restart; if the Brio feed fails permanently, the system switches to the secondary ArduCam feed. In the event of excessive network bandwidth usage, the system seamlessly reduces resolution (to 720p) and caps the framerate (to 20 fps) to preserve real-time control.

# C&C

- Design Choices and Component Selection
  - Team Oceanus uses a Logitech Controller in the mission station for the ROV as it is a highly affordable option as a controller with an ample selection of buttons and joysticks available to allocate to any operations needed to be done on the ROV.
  - On the float, Team Oceanus uses a Raspberry Pi Pico W as a microcontroller as it is one of the most affordable options with bluetooth capabilities and easy programmability. To create the embedded software required to automate the vertical profiling task. Python is used as it is one of the most flexible and easiest to learn coding languages. Using a VS Code extension called “MicroPico,” creating usable Pico W code is simple.
  - Team Oceanus uses an ultrasonic sensor to detect if there is an ice layer above the float in order to ensure that when resurfacing there will be no issues colliding with the ice as competition rules state that collision with the ice layer will result in a deduction of points. An ultrasonic sensor was the best choice for this task due to the operating temperature limitation the ice tank puts on all our components, an ultrasonic sensor was one of the few options available for reliable underwater sensing in temperatures as low as the ice tank.
- Crab image recognition (Task 2):
  - To determine the number of invasive European Green crabs in a given sample, the laptop will receive camera feed from the ROV and run programs locally on the laptop to allow for image recognition which will consist of a bounding box around each invasive crab along with the number of them. (EDIT LATER ONCE WE GET BETTER CLARIFICATION)
- Topside design:
  - The C3 station utilizes a laptop to control and monitor the ROV during tasks. This laptop contains the necessary hardware to ensure good performance while running software programs and outputting data. Transmission of data between the ROV and C3 station is reliably done through an Ethernet connection. To ensure a seamless ease of use for piloting control, incorporated into the station is a logitech controller connected to the laptop which allows control over gripper and thrusters for the ROV. Additionally, the laptop monitor will contain a graphical user interface that displays camera feeds, ROV data, and allow the running of programs necessary for tasks.
- Communication Architecture Design
- Embedded Software Design

# System Integration Diagram (SID)

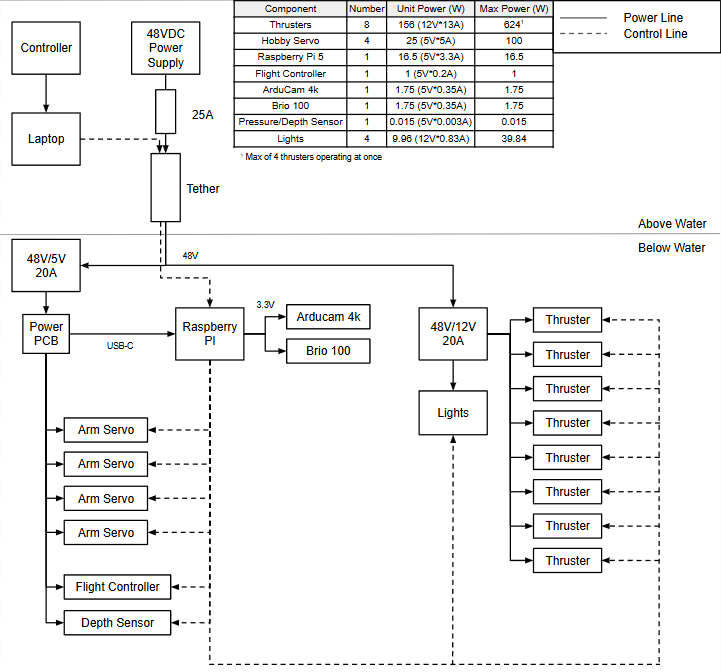
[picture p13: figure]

# Safety

- Personal

Prior to beginning the assembly procedure, all personnel were required to follow standard laboratory safety protocols. Each participant wore appropriate personal protective equipment for the duration of the experiment?, including safety goggles to protect the eyes from any small components or debris, a t-shirt covering the shoulders to protect exposed skin, long pants, and closed-toe shoes to guard against dropped components or equipment. These precautions ensured that all personnel remained protected throughout the electronics assembly process.

- Robot

The design and assembly of the underground ROV incorporated several precautions to ensure safe operation of the vehicle and protection of its components. Given the demanding nature of underground environments, materials were selected with durability and reliability in mind, prioritizing components rated for the expected operating conditions including moisture, pressure, and physical stress.

To protect the electrical system from overcurrent events, fuses were integrated into the circuit at critical points. These fuses serve as the first line of defense against short circuits or unexpected current surges, preventing damage to sensitive electronics and reducing the risk of fire or component failure during operation. Fuse ratings were chosen to match the expected current draw of each subsystem while still providing adequate protection.

All wiring and connections were carefully routed and secured to minimize the risk of shorts, disconnections, or mechanical stress during deployment. Waterproofing measures were applied to relevant electrical components and enclosures to prevent moisture ingress, which poses a significant risk in underground and subterranean environments. Prior to deployment, the ROV was inspected to verify that all connections were secure, all protective measures were in place, and the vehicle was functioning within expected parameters.

# Testing

# Accounting

The Bill of Materials began with a grant from TAMU Think Tank for $5.000, The team also had a $100 generous donation. These funds lead to a final budget of $5,100. Since this is the first year of Team Oceanus, all components are either donated or bought. The expenses and income was recorded in a google sheet. This sheet There was a cost buffer of 20%, this became crucial to deal with unforeseen shipping costs and tariffs. The costs for components were gathered online, with the cost of shipping covered in the buffer, The items accounted for in the travel estimates are approved estimates by the Texas A&M travel department. This includes unusual things like team merchandise, and gas.

Travelling expenses, cost accounting

BOM (whenever it is finalized)

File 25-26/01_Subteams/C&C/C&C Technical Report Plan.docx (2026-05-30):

Float:

Chris & Arnav: Explanation and inclusion of code and maybe make diagram of how code works

Andrei & Aarav: Put communication architecture design of float and explain how we connected everything (include data types and how we worked with them)

How sensors relate to mission requirements

- Material considerations affecting signal transmission (water interference, enclosure material)
- How did the temperatures affect our decision on which parts we were going to use

Chris & Arnav: Design rationale:

- Choice of Python
- Explanation of software (MicroPico)
- Raspberry Pico W (ensure to explain why we chose over alternatives like pi-5)
- Choice of using an ultrasonic sensor
- Float Communication method (Bluetooth) (ensure to explain why we chose over alternatives)

ROV:

Andrei & Aarav: Put communication architecture design of ROV and explain how we connected everything (include data types and how we worked with them)

Chris & Arnav: Design rationale:

- Selection of lights? (ensure to explain why we chose over alternatives)
- Selection of logitech controller (affordability and maybe button layout/how to do keybinds) (ensure to explain why we chose over alternatives like xbox controller)
- Communication protocols used (UART, I2C) and what each is responsible for
- Justification for protocol choices (UART vs I2C vs alternatives)
- Data types transmitted (control signals, sensor feedback, video data if applicable)
- Justification for chosen data format (structured, readable, easy to debug)
- crab image recognition software
  - CHECK WITH GNC ON THIS, they are working on the code for the ROV but I’m not sure if they are working on this portion
- Task management such as using github and google drive
  - This could be technically a whole team thing, not just C&C

Focus on later:

Test methods

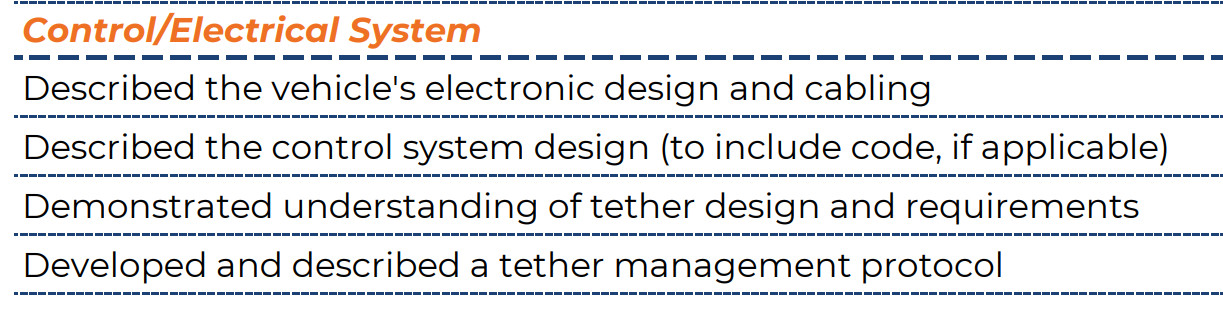
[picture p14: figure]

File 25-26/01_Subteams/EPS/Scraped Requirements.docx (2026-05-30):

Guideline | Page
Wiring discipline/workmanship (ELEC-023P) | 43
Strain relief at both ends of the tether (ELEC-024P) | 43
Safety In Design (SID) technical documentation does not show a main fuse | 43
Circuit boards, batteries, and components must be securely fastened | 43
Full Load Amps (FLA) must be included on the SID | 47
All electrical devices must be mapped on the SID | 48
If using 48-volts, an SBS50 Anderson Powerpole connector is the main point of connection to the MATE supply. If using 12-volts, a red-black Anderson powerpole connection is the main point of connection to the MATE supply (ELEC-010P) | 48
A properly sized fuse is within 30 cm of the main point of connection to power. If the company is using 48-volts, a properly sized Littelfuse must be used. If the company is using 12-volts, a properly sized ATO blade or Mini blade fuse must be used. The company must use a ruler to show this distance (ELEC-008P) | 48
Full load amps value and fuse size must be selected (ELEC-008P) | 49
The inside of the control box must not have exposed wiring (ELEC-017P) | 49
The control box must be neatly laid out with attention to workmanship (ELEC-022P) and a separation and identification of 120VAC wiring from DC and control voltages (ELEC-023P) | 49
The tether leading to the control system and the ROV must have adequate strain relief (ELEC-024) | 49
The tether must be capable of reaching 5.5m down and 8m out | 53
Only one of 48V or 12V may be chosen for the power supply | 54
All power provided externally must be from the power supply and pass through the provided fuse and the in-line fuse | 54
The ROV must use a specified in-line fuse (linked to in the guidelines), and the specified fuse holder if using 48V (for 12V, different fuses are required) | 54
All blade fuses must correspond to the standardized color codes | 54
The 48V power supply output may not be modified before reaching the ROV | 55
Voltage can’t be increased above the nominal voltage anywhere on the ROV | 55
Only specific types of batteries allowed (see guidelines for details if needed) | 56
Battery fuses and wiring is restricted (see guidelines for details if needed) | 57
The enclosure must open if the inside pressure is greater than outside | 58
Pressure release valves and pop off end caps are not allowed | 59
Independent sensors must have a 3 amp fastblow fuse on the positive side | 59
The 48V is limited to 30A, and the 12V is limited to 25A | 59
Use the provided tables for deciding on a fuse size | 60
The fuse must be connected before any E-stops or other safety systems | 61
For 48V, power supply connections will be Anderson Power Connectors, which must be securely connected to the ROV power wires | 62
The Anderson SBS50 connector is required (linked in guidelines) | 62
Tether must be of IEC standard type, and have a high and low voltage | 63
Electrical connections must be sealed from water | 64
If disconnected from the surface supply, the ROV must shut down in 5s | 65
All circuit board connections should be soldered or through terminal connections with screw or spring locks. Pin jumpers should not be used in the final system and will not pass safety inspection | 1 (EWP)

Sources:

Mate ROV 2025 Guidelines

https://20693798.fs1.hubspotusercontent-na1.net/hubfs/20693798/2025%20PIONEER%20Manual_FINAL_1_6_withCover.pdf

Mate ROV Expected Work Practices

https://20693798.fs1.hubspotusercontent-na1.net/hubfs/20693798/MATE%20ROV%20Competition%20Tech%20Bulletin%20-%20MATE%20Expected%20Work%20Practices.pdf

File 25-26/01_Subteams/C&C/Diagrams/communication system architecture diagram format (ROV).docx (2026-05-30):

# Entire

# C3 Station

ROV Pilot:

- The ROV pilot provides instruction and task to the Pilot-Computer Interaction Module

Monitoring Unit Information:

- Laptop
  - Powered by the AC power outlet provided.
  - Connects from ethernet cable port to the tether

Pilot-Computer Interaction Module

- Logitech controller
  - Will plug in to USB‑A port on C3 Station

ROV State Display Module

- IMU Information
- Stuff

Power:

- Wall outlet will connect to

# Tether:

Ethernet Cable

- Cat 5e Lan Cable
- Link (https://www.outlandtech.com/product-page/c-3400)

Power cable

- Link (https://www.amazon.com/Conductor-Electrical-Stranded-Extension-Automotive/dp/B0CN76L8G3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)

# ROV (Internal Components)

- Thermistors
- Blue Robotics IMU Navigator
  - (For both power and data it will specifically connect to the Raspberry Pi 5’s 40-pin GPIO header “J8”. Align pin 1 on the Navigator with pin 1 on the Pi 5 header (pin 1 is the 3.3 V corner nearest the USB‑C power jack))
- Raspberry Pi 5 will have the 5v power/ground line connected through the USB C port

Power:

- Printed Circuit Boards
  - (Connect each ESC signal wire to a Pico PWM GPIO like GP0 pin 1 or GP1 pin 2 and tie ESC ground to a Pico GND like pin 3. Provide 5V from the ESC BEC to Pico VSYS pin 39 if you want the ESC to power the Pico or leave VSYS unpowered and power the Pico by USB VBUS pin 40. Ensure all grounds are common and send standard 1 to 2 ms servo pulses.)
- 12V to 5V transformer(Will power Raspberry Pi 5)
  - Will be connected to Raspberry Pi 5, specifically use a 12V to 5V DC converter. Connect its 5V output to the Raspberry Pi 5 USB C power port or to the 40 pin header 5V on pin 2 or pin 4 and GND on pin 6 or pin 9 or any GND. Ensure the converter supplies 5V 5A and all grounds are common.
- 5V to 3.3V transformer (Will power Raspberry Pico W)
  - Will be connected to the regulator input to Raspberry Pi 5V on pin 2 or pin 4 and GND to any ground such as pin 6. Send the regulator 3.3V output to your 3.3V peripherals only and keep grounds common. Do not backfeed the Pi 3V3 pins with that output.

Data:

- stuff

# ROV (External Components)

Power:

- Arducam 4K Camera
  - The power will be provided through the Raspberry Pi 5.
- Brio 100 Camera
  - Powering the Brio 100 Camera would be through
- Lights
  - The lights will be connected to a Relay to the Raspberry Pi 5 to allow for turning the lights on and off.
- Diamond Dynamics Thrusters
  - Will be connected to port Microcontroller (Raspberry Pico W) specifically each ESC signal wire should be connected to a PWM capable GPIO on the Raspberry Pi Pico such as GP2 GP3 GP4 or GP5.
  - Tie the ESC ground to a Pico GND pin and share ground with the battery.
  - Feed battery voltage only to the ESC power leads and do not power the ESC or thrusters from the Pico 3V3 or VSYS pins.
- Hobby servos

Data:

- Arducam 4K Camera:
  - The Arducam 4K camera will be connected to the USB 2.0 port of the Raspberry Pi 5.
- Brio 100 Camera:
  - will be connected to the USB 2.0 port of the Raspberry Pi 5.
- Hobby Servos
  - Link (https://www.ebay.com/itm/285820436532?chn=ps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)
  - Used to control motion of Claw. It will be connected to the Raspberry Pi 5 GPIO Pins
- Claw
  - Claw will consist of 4 servos
- Stuff

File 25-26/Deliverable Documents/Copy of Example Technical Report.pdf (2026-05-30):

ATA Project No. 90460-008
May 5, 2024

This document contains ATA Engineering or client trade secret, confidential, and/or proprietary information. Any unauthorized release of this information is prohibited.

# Machine Learning for Liquid Rocket Engine Startup

Prepared by

ATA Engineering, Inc.
13290 Evening Creek Drive South San Diego, California 92128

ML for LRE Startup | Project No. 90460-008
ATA and/or CLIENT PROPRIETARY | ii

### Signatures and Contact Information

Prepared by:
Aiden Kampwerth
Project Manager
Aerospace Engineer Intern

Reviewed by:
Victoria Harris
Reviewer
AIML Technical Director

CONTACTS

ATA:
Aiden Kampwerth | 720.456.4170
aiden.kampwerth@ata-e.com
Emma Joly | 720.456.4152
| emma.joly@ata-e.com
Victoria Harris | 703.225.7447
| victoria.harris@ata-e.com

ML for LRE Startup | Project No. 90460-008
ATA and/or CLIENT PROPRIETARY | iii

## ABSTRACT

This report documents ATA Engineering, Inc.’s current and future work on Intelligent Gradient-based Neural-network for Ignition Timing Evaluation (IGNITE). IGNITE is a proof-of-concept software package aimed at predicting the open-loop ignition sequence for a liquid rocket engine (LRE) utilizing a reinforcement learning (RL) model and Siemen’s Amesim software. The RL agent predicts a stable ignition sequence utilizing Amesim as an environment from which it can learn, explore, and exploit properties of LREs at least as fast as a field expert. Current work involves testing the RL agent against simplified environments for verification and validation with future work entailing the application of the RL agent in the LRE environment and implementing significant performance improvements.

ML for LRE Startup | Project No. 90460-008
ATA and/or CLIENT PROPRIETARY | iv

## DOCUMENT REVISION LOG

Version | Description | Author | Date
1.0 | Initial release | A. Kampwerth / E. Joly | 5/3/2024
1.1 | Rev 1 | A. Kampwerth / E. Joly / V. Harris | 5/3/2024

ML for LRE Startup | Project No. 90460-008
ATA and/or CLIENT PROPRIETARY | v

## TABLE OF CONTENTS

ML for LRE Startup | Project No. 90460-008
ATA and/or CLIENT PROPRIETARY | vi

ML for LRE Startup | Project No. 90460-008
ATA and/or CLIENT PROPRIETARY | vii

## LIST OF FIGURES

ML for LRE Startup | Project No. 90460-008
ATA and/or CLIENT PROPRIETARY | viii

ML for LRE Startup | Project No. 90460-008
ATA and/or CLIENT PROPRIETARY | 1

## 1. INTRODUCTION

When developing Liquid Rocket Engines (LREs), an often-overlooked problem is the development of an open-loop control ignition sequence to transition an LRE from off to full throttle. This project aims to create a machine learning model capable of predicting an ignition sequence to augment the work of propulsion engineering experts which could save time, money, and potentially lives.

An aside, readers working on this project are heavily encouraged to review the training material in Appendix A. Basic terminology will not always have an explanation or reference example and uninformed readers may miss crucial details.

### 1.1. Background

LREs are not complex due to the number of components, but rather due to the strong inter-dependence of the few components there are. LREs must contain all of their subsystems onboard so utilizing multiple independent subsystems is both a waste of space and mass. Therefore, an intricately connected LRE is not only preferred but often necessary to achieve performance and efficiency metrics.

However, the inherent complexity of an LRE raises several challenges, with the primary concern being control. LREs experience some of the most extreme conditions known within sometimes only a few centimeters of each other. It is imperative that these conditions are managed correctly or rapid unscheduled disassemblies (https://www.youtube.com/watch?v=bvim4rsNHkQ) will occur.

Typically, control becomes trivial in steady state conditions, such as reaching a target Rated Power Level (RPL). Issues arise during the transient phase between steady state conditions where several components need to make significant changes to their internal conditions at the same time [11]. The relatively few control points (fluid valves) need to gradually move the internal states of components towards their target without exceeding numerous physical limits of the engine.

The primary occurrence of this transition is during LRE ignition right before launch. Failure to properly control the internal LRE state can lead to events like unstarts (https://www.youtube.com/watch?v=Fa7hTT9WMg4) where the combustion propagates upstream through the delicate components instead of being exhausted through the nozzle.

ML for LRE Startup | Project No. 90460-008

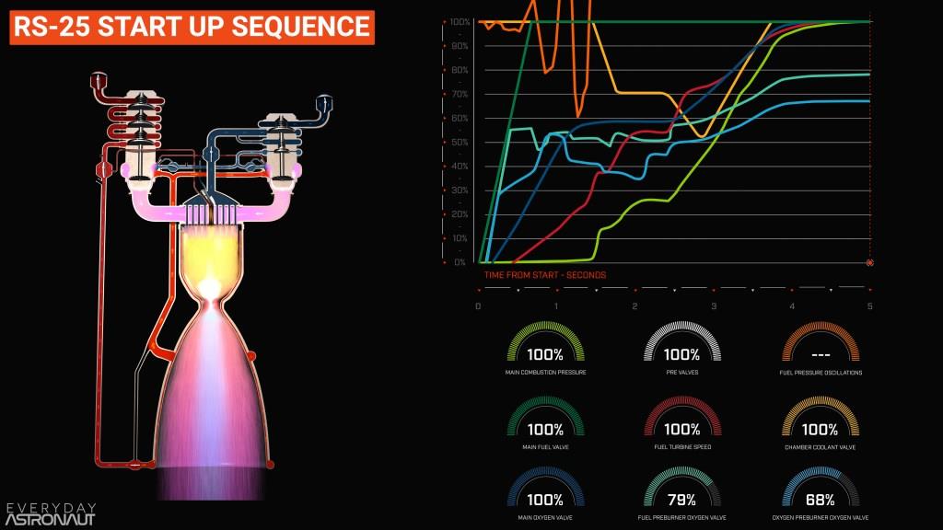
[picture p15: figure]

Figure 1-1. RS-25 ignition sequence [10].

Given the inexact understanding of a LRE’s transient state properties during the development phase, propulsion engineers often have to manually control the internal state to prevent failures. This is accomplished via an ignition sequence, a timing graph which dictates the position of fluid valves over the course of the ignition sequence as seen in Figure 1-1.

Even today, the only completely accurate way of determining the ignition sequence is through testing prototypes until one doesn’t explode. The RS-25’s development include over 50 static fire tests before it stopped exploding during ignition [13]. Propulsion engineers try to reduce the required number of static fires by using numerous calculations, simulation models, and often decades of field experience to determine a guess for what the ignition sequence should roughly be. This guess will be referred to as an initial ignition sequence for this project.

The required work to get an initial ignition sequence has barely decreased since the
development of the RS-25 in the 1970’s. Modern simulation software like Siemens’s Amesim (https://plm.sw.siemens.com/en-US/simcenter/systems-simulation/amesim/) (discussed further in section 2.1) has replaced NASA’s outdated ROCETS, (https://software.nasa.gov/software/MFS-31858-1) but little progress has been made to truly reduce the required work.

### 1.2. Problem Statement

Therefore, this project aims to generate an initial ignition sequence for any LRE utilizing only its design parameters and simulation model.

For a solution to this problem, the following requirements must be met:

ML for LRE Startup | Project No. 90460-008
- Generalizability
- Precise control
- No additional information or analysis
- At least as fast as an expert

These requirements led to the use of a Reinforcement Learning (RL) agent, capable of learning any LRE through trial and error and only given the simulation model with a reward structure (discussed further in section 3).

The RL agent combined with the Amesim environment is wrapped into the Intelligent Gradient-based Neural-network Ignition Timing Evaluation (IGNITE) software.

As for the specific LRE, the RS-25 was chosen due to being a pre-built Amesim model and the numerous publicly available documents regarding its development. This is not typical for LREs as their information is usually proprietary and therefore inaccessible. Even given the open nature of the RS-25, much of the raw data is kept with NASA’s subcontractors, hence the need for machine learning methods which generate their own data.

### 1.3. Applications

For the majority of LREs, their complexity directly correlates to a more difficult ignition sequence. The most performant LREs, such as a full-flow staged combustion cycles (https://en.wikipedia.org/wiki/Staged_combustion_cycle) (FFSC), have historically been exceptionally difficult to control properly. Currently, SpaceX has been the only organization to develop a FFSC LRE verified for orbital flight (Raptor) (https://en.wikipedia.org/wiki/SpaceX_Raptor) partly due to the ignition sequence they found. Therefore, IGNITE would enable other organizations to develop their own FFSC LREs much faster and directly compete with SpaceX.

Figure 1-2. Starship exploding due to several Raptor engine failures [15].

ML for LRE Startup | Project No. 90460-008

A separate issue when designing LREs are determining failure modes. Only after an ignition sequence is found can propulsion engineers accurately predict failure modes and improve the design [8]. However, this is often an afterthought as a majority of the failure modes are discovered trying to find the ignition sequence. For example, SpaceX’s Integrated Flight Test (IFT) 1 had several separate LRE failure events occur which resulted in the termination of the flight.

IGNITE would allow for a shift to determine failure modes before any prototypes need to be created. Designers can then use the results they gathered to implement or modify features in the LRE design to prevent disasters like in Figure 1-2.

ML for LRE Startup | Project No. 90460-008

## 2. SIMULATION ENVIRONMENT

The RL agent requires an environment to work in which can be accessed through Python. This section addresses the following:

- The specifics of the simulation environment, Siemens’ Amesim
- Representation of the RS-25 in of the simulation environment
- How the simulation environment can be imported into the main program

### 2.1. Amesim Platform

Siemens’ Amesim is a simulation software platform developed primarily for use in modeling and analyzing multi-domain systems. It allows engineers to perform simulations of mechanical, hydraulic, pneumatic, thermal, and electrical systems within a single integrated environment. The platform is particularly valuable for its ability to help predict the behavior of the systems and optimize their performance before actual physical prototypes are built.

The optimization and prediction capabilities are the inspiration for this project and are used in a variety of ways to achieve our end goal.

### 2.1.1. Components

Amesim’s primary building blocks are components which each model a specific subsystem within an overall system.

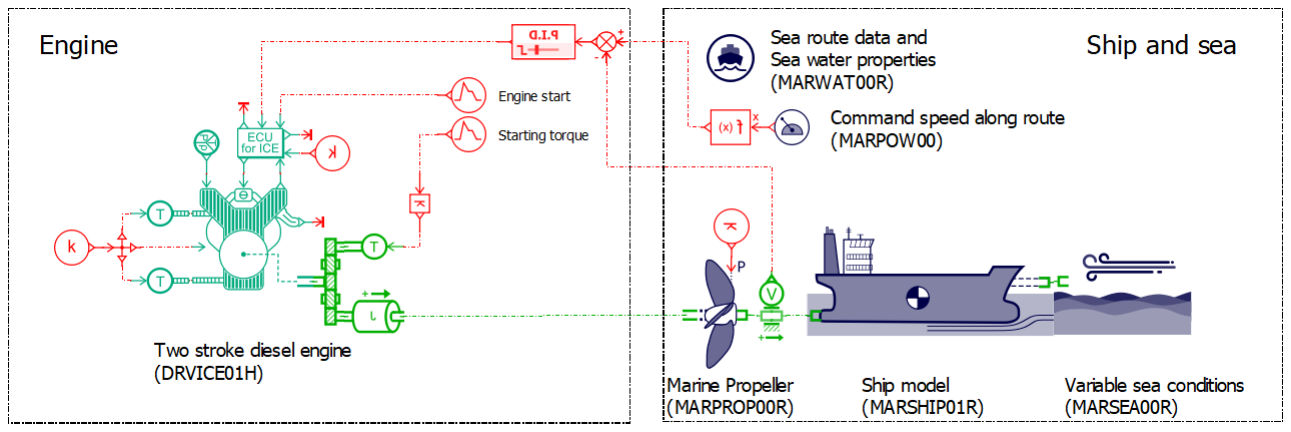
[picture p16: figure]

Figure 2-1. naval ship and engine modeled in Amesim [20].

ML for LRE Startup | Project No. 90460-008

For example, in Figure 2-1, the ship’s diesel engine is represented with multiple rotary components (colored in green), fluid-mechanical components (colored in turquoise), and wiring components (colored in red).

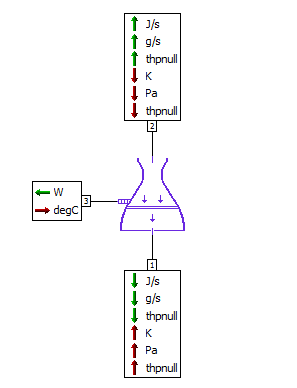
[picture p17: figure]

Figure 2-2. Liquid Propulsion libraries’ nozzle component port diagram.

All of the components have input-output ports which allows information to flow across the model. These are represented by the red and green arrows in Figure 2-2. All component ports in a model must be connected in order to properly transmit information and create a closed system.

Some components are general representations of a subsystem and therefore a specific submodel must be assigned to capture the appropriate dynamics of the system. This also can simplify certain models by combining multiple components for a subsystem into a single general component with a submodel.

### 2.1.2. Libraries

Amesim categorizes its components into libraries which each serve a general domain. For this project, the Liquid Propulsion, Thermal, and Two-Phase Flow libraries provided the majority of components required to model the RS-25.

ML for LRE Startup | Project No. 90460-008

Figure 2-3. RS-25 oxygen pre-burner Amesim model.

Two-Phase Flow provides all of the components that directly handle the transportation and manipulation of fluids throughout the LRE. (red/blue/yellow/brown lines connecting components)

Liquid Propulsion contains the major LRE components such as the combustion chambers, nozzles, turbines, etc. (colored in purple)

Thermal provides components responsible for thermal management. (colored in brown)

### 2.1.3. Variables

The primary way Amesim models the interaction of components is through state variables (refer to Figure 2-2). Each component has state variables which are governed by Ordinary Differential Equations (ODEs) specific to the component. Therefore, when state variables are coupled together in a model, a system of ODEs is formed which an ODE integrator can solve numerically.

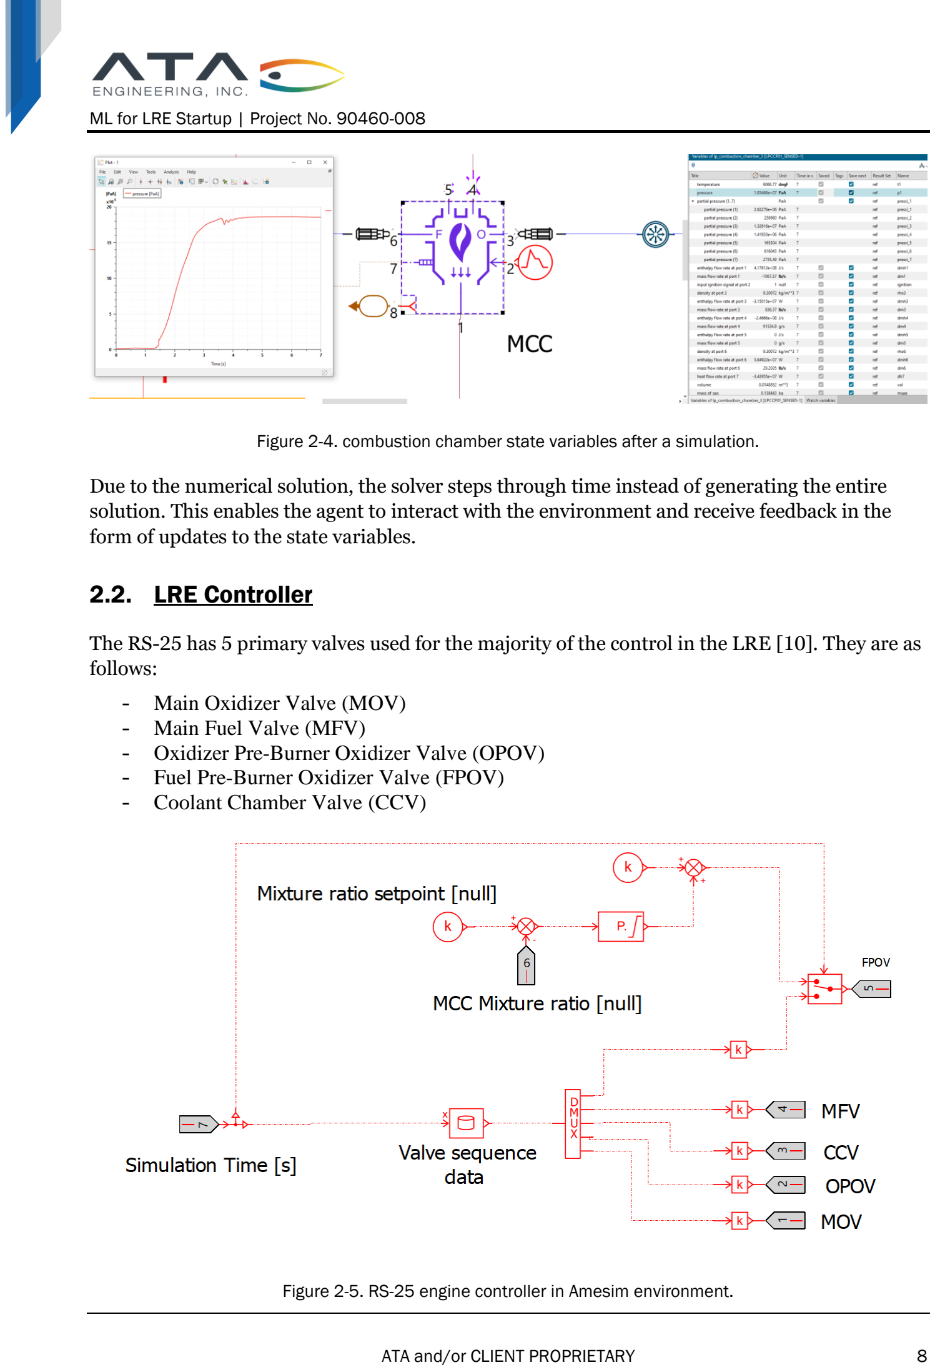
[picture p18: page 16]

ML for LRE Startup | Project No. 90460-008

Figure 2-4. combustion chamber state variables after a simulation.

Due to the numerical solution, the solver steps through time instead of generating the entire solution. This enables the agent to interact with the environment and receive feedback in the form of updates to the state variables.

### 2.2. LRE Controller

The RS-25 has 5 primary valves used for the majority of the control in the LRE [10]. They are as follows:
- Main Oxidizer Valve (MOV)
- Main Fuel Valve (MFV)
- Oxidizer Pre-Burner Oxidizer Valve (OPOV)
- Fuel Pre-Burner Oxidizer Valve (FPOV)
- Coolant Chamber Valve (CCV)

Figure 2-5. RS-25 engine controller in Amesim environment.

ML for LRE Startup | Project No. 90460-008

Figure 2-5 depicts how all 5 valves are integrated within the Amesim environment. The goal of the project is to replace the “valve sequence data” container with an agent capable of controlling all the valves at each instance.

The following sections analyze the macro properties of the RS-25 with relation to the valve control to improve the performance of the agent.

### 2.2.1. RS-25 Valves

The MOV and MFV control the total flow of oxidizer and fuel into the entire LRE, respectively. The RS-25 uses a staged combustion cycle with two fuel rich pre-burners which means all the fuel runs through the pre-burners while only part of the oxidizer does.

Therefore, the missing pre-burners’ fuel valves are accounted for by the MFV. Consequently, the inherent lack of control over the fuel in the LRE forced the designers to set the position of the MFV as a design parameter. This eliminates the need for the agent to model the MFV entirely.

Furthermore, the oxidizer flow into the pre-burners is controlled by the OPOV and FPOV which are fed by the MOV. The MOV can then be modeled to be the sum of the required mass flow rates (MFR) of the pre-burners and the requested MFR of the main combustion chamber (MCC). Therefore, the MOV can be directly associated with control of the MCC’s oxidizer.

As an aside, the CCV only re-directs a part of the fuel flow towards the LRE’s nozzle walls to cool the engine down. This fuel is then reintroduced to the main flow after passing around the nozzle with the only major difference between the two being the temperature of the fuel. The added rise in temperature of the fuel is considered a design parameter and its control is only associated with maintaining a specific temperature in the nozzle.

The pre-burners are directly associated with several major components in the LRE and thus their internal state is particularly important to LRE stability. Given the other three valves are considered design parameters, the OPOV and FPOV are the primary control points for the RS-25.

Combining these notes together enables the creation of relevant reward systems in the agent without compromising generalizability of IGNITE.

ML for LRE Startup | Project No. 90460-008

### 2.2.2. RS-25 Reference Ignition Sequence

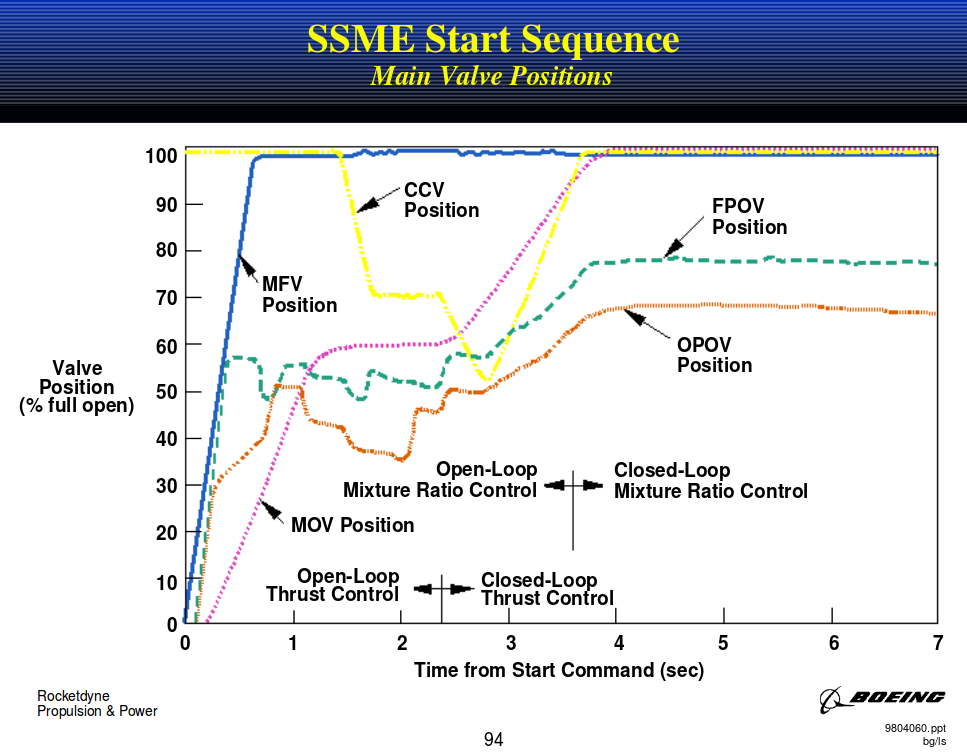
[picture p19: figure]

Figure 2-6. SSME reference ignition sequence [16].

Figure 2-6 displays the 5 primary valves’ position over the duration of the ignition sequence.

The MFV, MOV, and CCV follow a particular pattern of moving towards a position and holding at that position for some period. This is due to these valves being design parameters and therefore only adjusting to major changes in the internal state.

The OPOV and FPOV are instead highly variable and are used to account for minor changes in the internal state. They still follow the pattern of the 3 previous valves; however, they operate in a region around the target position instead of a fixed value.

The two separate behaviors are classified as fixed and variable valves which can be applied to LREs regardless of number of valves or complexity. Modifying the agent to exploit these behaviors can significantly reduce training time compared to modeling each valve across the entire domain.

ML for LRE Startup | Project No. 90460-008

### 2.2.3. Open Loop vs. Closed Loop Control

The goal is to model only the open-loop part of the ignition sequence as a closed-loop region is not directly controlled by the designers. The RS-25 has two closed-loop regions: Thrust Control and Mixture Ratio Control.

The mixture ratio control region watches the mixture ratio (MR) in the MCC and adjusts the FPOV valve accordingly to keep a MR of 7. The RS-25’s computer has little to no added input in this region and the LRE is in a steady state (SS) condition.

The thrust control region is more nuanced and only occurs after specific control laws become applicable. The designers of the RS-25 tested the LRE numerous times before being able to accurately control the LRE in this region solely based on computer commands. Therefore, the final software package should include the ability to model this region, however, the IRAD will not model the thrust control region for simplicity’s sake.

In summary, the agent will only model the valve positions until a target internal condition is reached. This internal state will function as an overall stability criterion in addition to aiding in the reward structure for the agent.

### 2.3. Functional Mock-up Interface

While Amesim has an internal python console, accessing it and manipulating state variables proved to be difficult and unnecessary. Amesim provides a more user-friendly approach through the Functional Mock-up Interface (FMI). (https://fmi-standard.org/docs/3.0.1/) FMI is an industry standard format for simulation models which facilitates inter-software compatibility.

### 2.3.1. Functional Mock-up Unit

FMI models are defined as Functional Mock-up Units (FMUs) which are a combination of C code and XML files. The C code contains the system of ODEs, state variables, inputs, and outputs from the original simulation platform. The XML files provide a description of the FMU and other, non-relevant secondary functions.

### 2.3.2. FMU Model Types

A majority of FMUs can be split into Co-Simulation (CS) and Model Exchange (ME) model types.

ML for LRE Startup | Project No. 90460-008

Figure 2-7. Model Exchange diagram [17].

ME is the most basic version of an FMU and primarily used for importing/exporting between independent simulation platforms. The main benefit is the control over the solver’s behavior in additional to not requiring a license from the exporting platform to run. Consequently, the drawback is the requirement for developing a solver capable of running the FMU.

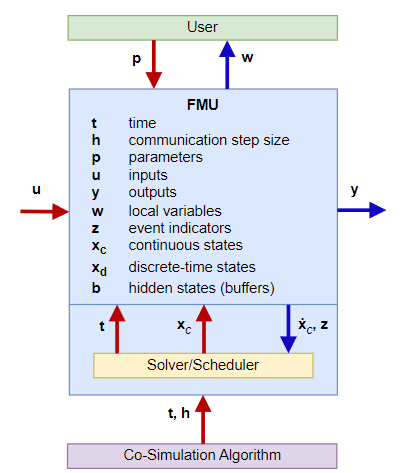
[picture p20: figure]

Figure 2-8. Co-Simulation diagram [17].

ML for LRE Startup | Project No. 90460-008

CS directly provides the opposite approach with the exporting platform’s solver integrated into the FMU. While requiring a license on hand, this allows the user to implement the FMU outside of a standard simulation platform.

Naturally, a CS model type was chosen due to the significantly reduced requirements for initial testing. However, this may need to be re-evaluated in the future dependent on IGNITE’s final integration level within Amesim.

### 2.3.3. FMI Integration in Amesim

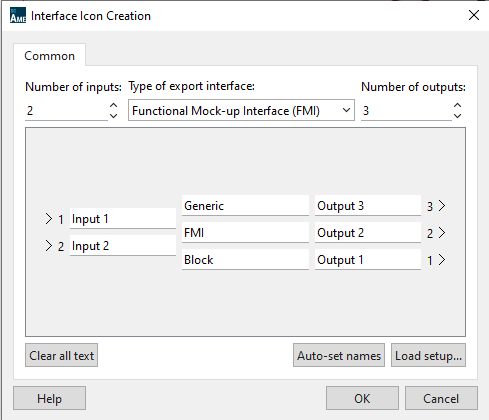
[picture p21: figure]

Figure 2-9. Amesim FMI interface component.

Amesim’s FMI component block defines the inputs and outputs for the FMU. When implementing the FMU, the outputs of the component become the inputs into the FMU and vice versa.

ML for LRE Startup | Project No. 90460-008

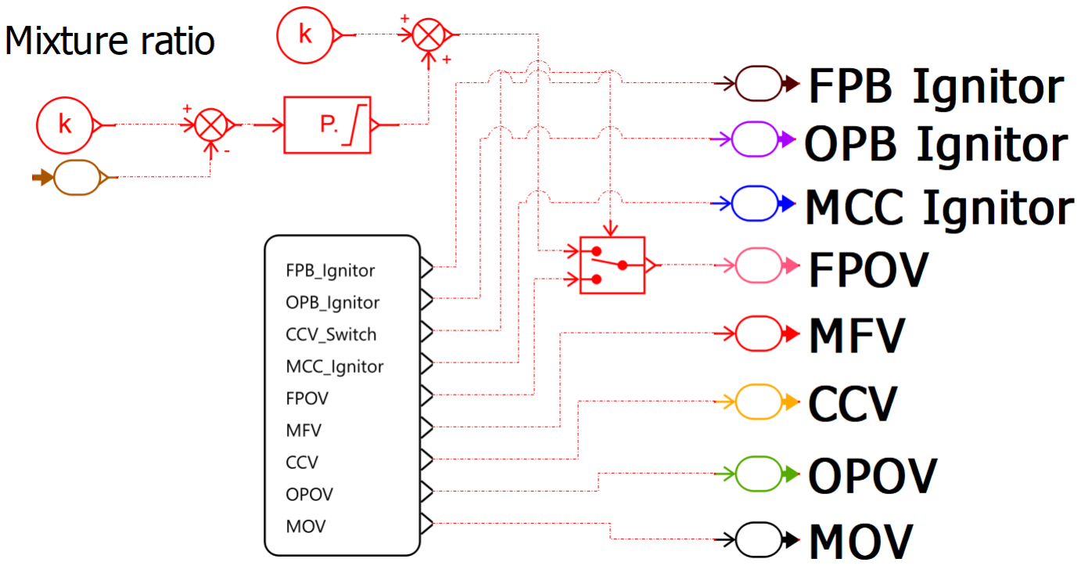
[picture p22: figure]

Figure 2-10. RS-25’s engine controller.

Typically, the model returns some output to be used in a larger simulation model. However, the agent needs access to all of the state variables while maintaining the system of ODEs. Therefore, as seen in Figure 2-10, there are no inputs into the FMU component block. Instead, the visibility of the FMU is set to high which allows the agent access to all state variables in the model without explicitly labeling them as outputs into the agent.

A quick aside, the MCC, OPB, and FPB Ignitors refer to the switches on each CC which ignites the products inside the CC and starts combustion. In the demo model, these are set to known values, however the agent will need to determine the stability of each CC before enabling the ignitor. This allows for additional flexibility in the agent’s solution and potentially improving the performance compared to the reference ignition sequence.

ML for LRE Startup | Project No. 90460-008

## 3. REINFORCEMENT LEARNING AGENT

Reinforcement Learning (RL) is a semi-supervised type of machine learning where an agent interacts with some environment through actions and receives a state and rewards from that environment [1].

Figure 3-1. generic RL diagram [18].

RL has the benefit of generating its own training data in addition to approximately matching how humans learn through trial and error. Given the inherent lack of training data as well as trying to maintain a generalizable approach, RL is suited as a solution for this project.

### 3.1. Soft Actor-Critic Architecture

Out of the multitude of deep RL architectures, the Soft Actor-Critic (SAC) architecture was chosen due to its stability in large state spaces in addition to the maximal training efficiency [4].

ML for LRE Startup | Project No. 90460-008

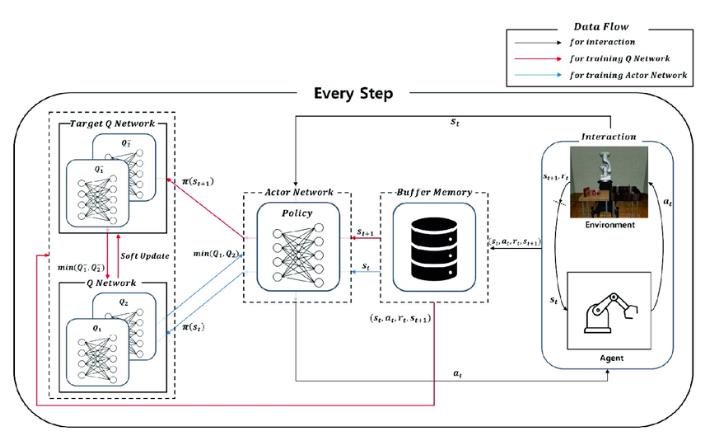
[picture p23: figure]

Figure 3-2. Soft Actor-Critic overview diagram [19].

This is achieved through the augmentation of an Actor-Critic architecture where an entropy parameter is introduced into the training procedure. The entropy of the system is related to the balance between exploration and exploitation of the actor’s current policy and it allows for the dynamic exploration of the state space until an optimal policy is found. Importantly, the implementation does not detract from the critic’s understanding of the environment which allows it to utilize all learned experiences, including those gathered with sub-optimal policies.

### 3.1.1. Actor Network

The actor is a standard Deep Neural Network (DNN) which makes stochastic actions compared to standard discrete actions. To retrieve an action, the associated LRE state is sent forward through the NN layers and the actor returns two parameters: mu and sigma.

Given the stochasticity of the agent, mu and sigma represent the parameters of a standard normal distribution for each valve. Mu represents the mean of the distribution while sigma represents the standard deviation. Given the standard deviation must be positive, non-zero, and not large (>>1), the sigma parameter is clamped to a range of some epsilon (1e-6) to 1.

The resulting distributions are then sampled via the reparameterization trick (https://gregorygundersen.com/blog/2018/04/29/reparameterization/) to enable differentiability for backpropagation (training) later. The samples for each distribution are the

ML for LRE Startup | Project No. 90460-008

actions the agent will take; however, they range from -∞ to ∞ which cannot be easily translated to a physical system. Therefore, a hyperbolic tangent function is applied to map the action space from -1 to 1 which represents the maximum closing and opening rates of the values respectively.

Additionally, as a feature of SAC, the joint log probabilities between the distributions of all the valves are computed (with a correction for the hyperbolic tangent squashing) which represent the total entropy of the actions. The agent then utilizes the entropy to inform itself on the viability of a current policy against the possibility of a more optimal policy.

### 3.1.2. Critic and Target Critic Network

The critic is a standard Deep Quality Network (DQN) which evaluates the actor’s actions against a state to determine a “quality value” of that state-action pair. The quality value (q-value) acts as a reward for the actor to maximize through learning an optimal policy.

Given the critic acts as the judge for the actor, it needs to be training on the state space to give an accurate analysis of a state-action pair. In other words, while the actor learns the behavior of its actions against a state, the critic learns the evolution of the states given an action. Therefore, the critic needs a value function to learn the ground truth behavior of the environment.

SAC utilizes a separate target critic network in order to act as the value function which is updated via a rolling average of the previous critic weights. This stabilizes training significantly by preventing the critic from losing valuable information, even from suboptimal policies or inaccurate q-values. This has a few drawbacks, especially when the critic over-trains over a specific reaction in the system, however it proves to be overall more advantageous to the agent’s training.

### 3.1.3. Entropy Parameter

The final learnable parameter is the entropy term (sometime referred to as temperature term) which dictates the ratio between exploration and exploitation of a policy. This term is applied to the entropy (joint log probabilities) of the actor’s action to modify their impact in the training procedure. As the entropy term approaches zero, the entropy is no longer a factor and the agent essentially follows the Actor-Critic architecture or fully exploitive. As the entropy term increases, the agent attempts to explore more of the state space.

ML for LRE Startup | Project No. 90460-008

### 3.2. Training Structure

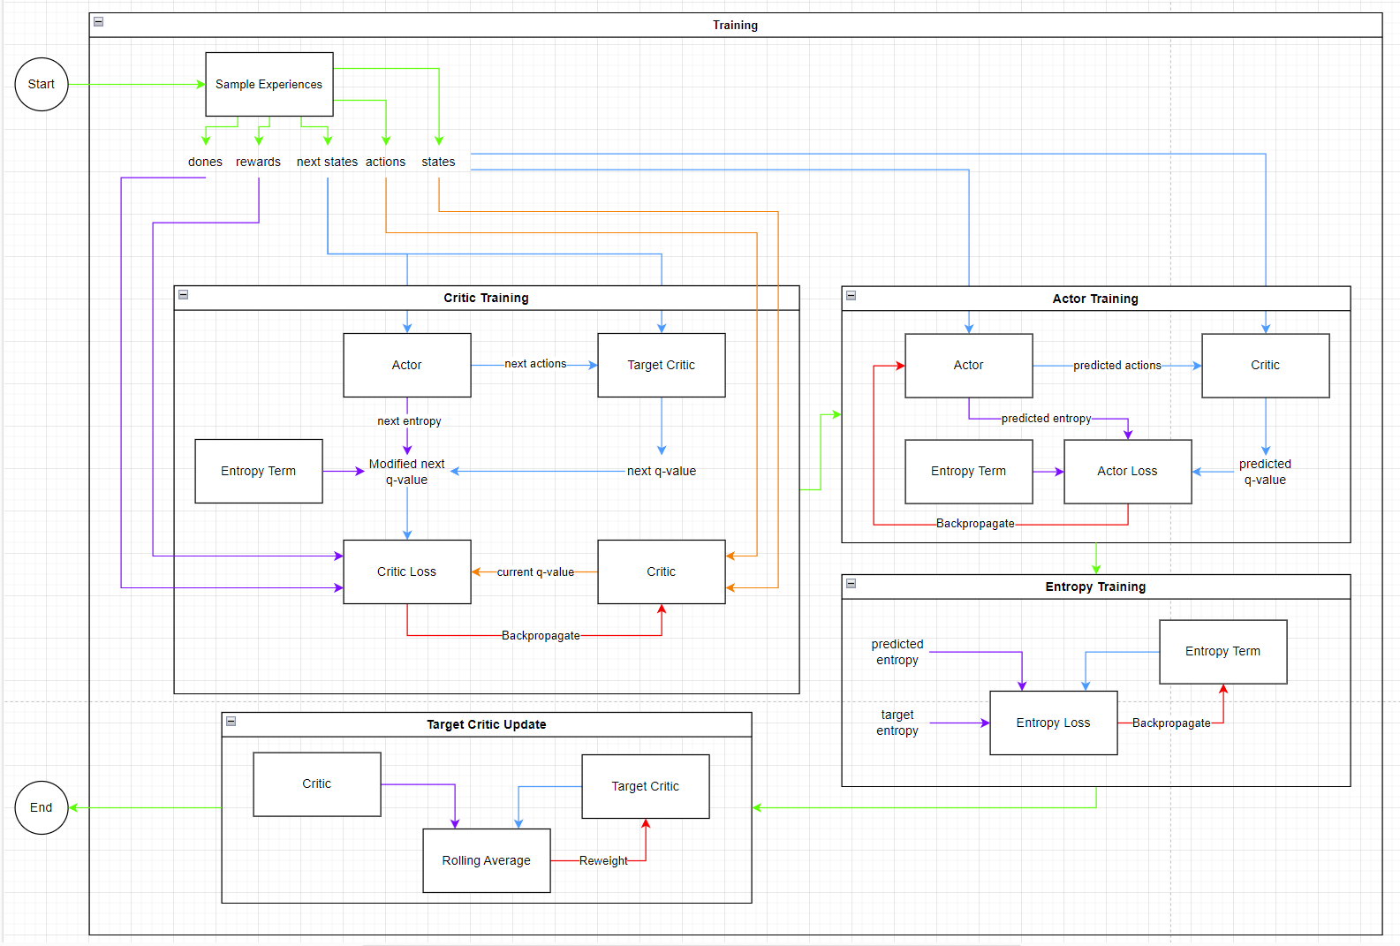
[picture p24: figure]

Figure 3-3. Soft Actor-Critic overall training diagram.

The following sections will explain the overall training procedure for the SAC architecture by breaking Figure 3-3 into individual sections in chronological order. This is important as updates are ordered to promote a policy-free based approach which requires the information to flow from the value network to the critic networks to the actor networks to any remaining parameters.

An important note about the colors in this section’s diagrams:
- Green: Chronological flow in overall diagram
- Blue: Primary flow in each subsection
- Orange: Secondary flow in each subsection
- Purple: Modifies attached component
- Red: Updates attached component (always occurs last)

Before any networks are trained, the experiences from the agent’s internal memory must be parsed into the following separate components:
- States

ML for LRE Startup | Project No. 90460-008
- Actions
- Next States
- Rewards
- Dones

The original of these components are specified in section 4.3. States contains the initial state of the environment for a given experience. Actions contains the agent’s actions given that initial state. Next States contains the resultant environment state after the actions are applied. Rewards contain the reward associated for the agent actions and resultant environment state. Dones contains the internal flag whether the simulated run ended.

An aside, each of the components above are arrays pulled from many individual experiences from the simulation loop. The calculations in the following sections are using the components in array form and then combining them together for the backpropagation or update step.

### 3.2.1. Critic Training

Figure 3-4. critic training diagram.

The first event in training is the calculation of the value function and applying it to the critic network. The value function is computed via Bellman’s Equation (https://en.wikipedia.org/wiki/Bellman_equation) which requires determining the future value to update the current value.

ML for LRE Startup | Project No. 90460-008

This starts with the actor network passing in the next states to determine the next actions it would have taken in the simulation loop. The next state-action pair is then passed into the target critic network to determine the next q-value.

Currently, the next q-value is directly linked to environment which would be passed into Bellman’s Equation in an Actor-Critic architecture. However, SAC decreases the next q-value by introducing entropy, under-valuing the evaluated quality of the next state-action pair. By under-valuing the quality, the agent is essentially leveling the quality of the current policies to prevent immediate exploitation of the current optimal policy.

Additionally, the next q-value is modified separately from the target critic, meaning the weights that resulted in the next q-value remain untouched. This allows the agent to decrease the entropy parameter and recover the exploitation of the optimal policy without having to significantly retrain.

V(si

) = R(si+1

) + γV(si+1)

Equation 3-1. simplified Bellman’s Equation.

The value function is then calculated following Equation 3-1 where si
represents the initial state, si+1 represents the next state, and V(x) represents the value function given some state x. The future value function, V(si+1), is the modified next q-value computed by the target critic network. The ground truth of the behavior is introduced via the reward associated with the next state and is represented by R(si+1). The discount factor, γ, reduces the value associated with the modified next q-value to promote maximizing current rewards over future rewards.

Separately, the initial state-action pair is passed through the critic network to determine the current q-value. The squared difference (MSE) between the computed value function (target q-value) and the current q-value is the critic loss. Finally, the critic loss is backpropagated through the critic network to update its parameters.

The critic loss represents the difference between true behavior of the environment and what the critic network believes the behavior of the environment to be. Therefore, the goal of the agent is to minimize the critic loss as that would signify the critic network is able to accurately predict the resulting quality of a given state-action pair.

ML for LRE Startup | Project No. 90460-008

### 3.2.2. Actor Training

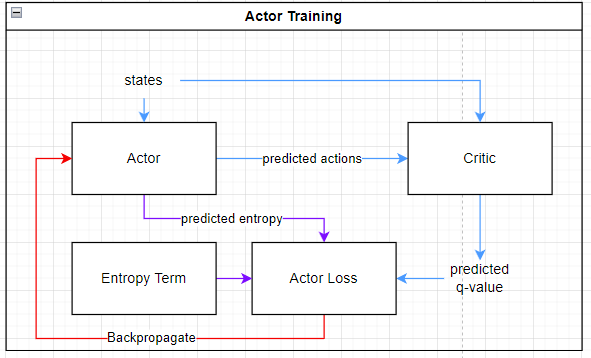
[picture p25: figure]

Figure 3-5. actor training diagram.

Using the newly updated critic network, the actor’s loss can be calculated. The initial state of the environment is passed through the actor to generate it’s predicted actions and associated entropy. The critic evaluates the initial state-predicted action pair and produces a predicted q-value.

Similar to the critic network training, the q-value is modified to include the entropy of the actions to under-value the quality of the current policy. Given the modified q-value is directly used as the actor’s loss, new properties arise from introducing the entropy.

The goal of the actor remains the same which is to minimize its loss function which in turn represents maximizing its quality. However, the entropy modification decreases the q-value which increases the loss function. The result is that the loss function is now bound from -∞ to ∞ instead of strictly negative. Therefore, a positive actor loss represents promoting exploration while a negative actor loss represents exploiting the current policy.

This representation is confirmed during backpropagation where positive losses correlate to negative gradients, essentially rolling back parameters to find new paths to explore. Negative losses correlate to positive gradients, reinforcing the current policy by strengthening the parameters.

ML for LRE Startup | Project No. 90460-008

### 3.2.3. Entropy Training

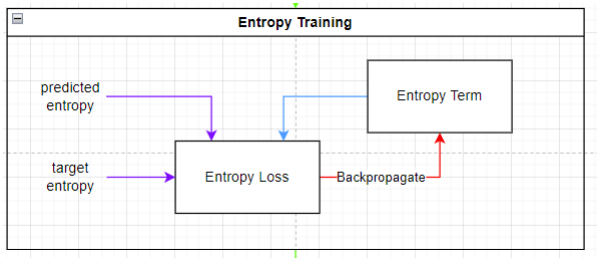
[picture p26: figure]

Figure 3-6. entropy training diagram.

For this project, the entropy term is a trainable parameter to promote dynamic exploration of the policy space. A target entropy term is utilized to promote the training to converge towards an optimal policy, typically the negative of the action space. The entropy term must remain positive so the difference between the target entropy and predicted entropy from the actor training is multiplied by the log of the entropy term. The resulting value is the entropy loss which is backpropagated through the single node.

When turned into a trainable parameter, the entropy term has a host of unique behaviors which depend significantly on factors like rewards, actor, and critic behavior. Further details with examples are discussed in section 5.2.

### 3.2.4. Target Critic Update

Figure 3-7. target critic update diagram.

ML for LRE Startup | Project No. 90460-008

Finally, the target critic network is updated with the new critic network parameters modified by a parameter τ (5e-2). The critic parameters are multiplied by τ while the target critic parameters are multiplied by 1 − τ and both are summed together to get the new target critic network parameters.

An aside, the target critic and critic networks are actually 4 networks in total, 2 for each type. This is done to prevent an overestimation of the q-value which is typical for RL agents to experience. The minimum of the two networks is used at each step to reduce the overestimation as much as possible. Additionally, this stabilizes the q-value between training events as oscillatory behavior is common when the agent approaches zero loss but the learning rate remains large.

### 3.3. Reward Structure

The reward encoder consists of a set of prime checks, a reward function, and a stability check. The current state variables, valve positions, current time, stop time, and a set of Booleans indicating the ignition prime status of each combustion chamber (CC) are used to compute the rewards. A set of scaling factors is defined by a user defined value and used to weight the importance of each reward on stability.

The reward encoder iterates over each CC and increments either transient or ignition rewards based on the prime check. Individual rewards are assigned as a scaled percentage of the target, with negative rewards assigned for violations [8]. The total rewards are equal to the sum of all the individual rewards.


Figure 3-8. target value reward function.

ML for LRE Startup | Project No. 90460-008

### 3.3.1. Prime Checks

Each CC has its own ignition check. The function first checks if the chamber has already been primed. If not, then the function checks that the MR is less than 1.5 times the target value [4]. The result is used to determine whether the reward encoder should assign transient or ignition rewards for each chamber. The correct MR ensures an oxygen rich environment, which is necessary to avoid explosions in the CC and other failure modes such as engine unstart [6].

### 3.3.2. Transient Rewards

If the LRE is in the transient state, individual rewards are assigned for the CC MRs and pressure increases. The current MR of the CC is compared against a target and rewards are assigned based on closeness to the target. The MR reward encourages the agent to approach the prime check conditions so the simulation can progress. The current pressure of the CC is compared to previous pressure values. The difference between the current and previous pressures are scaled and rewards are assigned accordingly. In the transient stage, pressure should be continuously increasing, rather than staying around target [2]. If the MCC is not primed, individual rewards are also assigned for the Mach number in the nozzle throat approaching a choked value. This is necessary for stability in the ignition stage [12].

### 3.3.3. Ignition Rewards

If the LRE is in the ignition state, individual rewards are assigned for the CC pressure and temperature according to how close they are to the target. Ideal temperatures and pressures affect thrust performance but are simpler for the agent to control simply by opening and closing valves [12]. If the main combustion chamber is primed, rewards for delay pressure and temperature are calculated. The pressure and temperature deviation are equal to the reward multiplied by a delay power. The reward is assigned as a product of the deviation and percent of the total time the episode has progressed. Delay pressure rewards are also assigned for the pre-burners. Delay rewards discourage the agent from overshooting the goal and exploiting temporary peaks in rewards [14]. If all of the CCs are primed, individual rewards are assigned for valve positions and pump rpms according to closeness to some target. The valve position reward discourages the agent from opening certain valves to the maximum position and closing certain valves to “cheat” the rewards. Instead, the valves are rewarded for increasing and staying around the closed-loop positions, while allowing for some movement around the target which is necessary for stability. The pump rpm reward is directly related to the pressure rise and head rise across each pump, which relates to pump efficiency [9]. The reward also acts as a reasonable check for leakage, which would cause the pressure to fall much shorter from the target [7].

ML for LRE Startup | Project No. 90460-008

Figure 3-9. target delay reward function.

### 3.3.4. Violations

Violations are assigned as negative rewards (penalties) and calculated by the state variables handler. The variable handler compares each system variable to its hard limit and assigns a penalty when a hard limit is exceeded [8]. These hard limits either correspond to physical limits, such as 0 K, or operational limits for each component, defined by the user. The total penalty is the sum of all individual penalties and applied as a negative reward in the reward encoder.

Figure 3-10. violation penalty function.

ML for LRE Startup | Project No. 90460-008

### 3.4. Agent Hyper-Parameters

Agent hyperparameters refer to any manually tunable term in the agent that affects its performance and behavior during training. Optimization of them can reduce maximal policy search times, prevent agent divergence, and increase training efficiency.

### 3.4.1. Learning Rate

A feature of all DNNs, the learning rate (LR) modifies the gradient in the backpropagation to damp the parameter weight update. The primary intend is to prevent overshooting global maximums while encouraging exploration of the state space. LRs tend to vary between 1e-5 and 1e-1 with the authors of the original SAC paper choosing 3e-4 as an initial heuristic.

Simpler environments with well defined global maximums can opt for an initially large LR to speed up training, however more complex environments require lower LRs to prevent losing valuable information through large gradients. Some amount of tuning with always be required to find the optimal LR, but the benefits typically overshadow the effort required.

### 3.4.2. Entropy Scale

The target entropy can be scaled up or down through the entropy scale factor. A higher entropy scale promotes a more exploitative policy compared and vice versa. The entropy scale can therefore be assumed as a measure of randomness for a converged policy. In section 6.1.1, an entropy scale of 4 was utilized to promote a final deterministic policy.

### 3.4.3. Training Threshold

The training threshold is an integer to determine how many experiences are required to be gathered before training the agent. The simpler the environment, the less experiences are required to determine the overall behavior and therefore the lower the training threshold. The opposite is also true with more experiences being required for complex environments and therefore a higher training threshold. This project currently uses 24,000 experiences and samples 2,400 experiences; however, it is likely to change due to improvements listed in section 7.

### 3.4.4. Network Layer Size and Depth

A DNN’s layer size and depth refers to the number and arrangement of the nodes in the DNN’s hidden layers. Size is the number of nodes in a given layer and depth is the total number of layers in the system. Depending on the complexity or form of the environment, different sizes and depths are used with smaller ones for simpler environments and large ones for complex environments. This project specifically uses 256 nodes and 2 layers as an initial heuristic, but more testing will likely result in a need to increase both size and depth.

ML for LRE Startup | Project No. 90460-008

## 4. IGNITE STRUCTURE

IGNITE has three main capabilities: an interface with the FMU, a training loop that returns the valve control sequence guess, and a set of post processing capabilities. IGNITE interfaces with the FMU through variable handling to standardize units and magnitudes across all environment variables. The training loop is comprised of two loops. The step-by-step processing occurs in the individual episode loop, while the general agent training processing occurs in the main loop. As episodes are simulated and stored, the agent will eventually fill up its internal memory and starts training on the experiences. The agent repeatedly trains in episodes until it reaches the desired initial ignition sequence. Post processing is done to display the losses, rewards, and valve control sequences so the user can come to their own conclusions about the results and adjust the training parameters to improve the model.
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

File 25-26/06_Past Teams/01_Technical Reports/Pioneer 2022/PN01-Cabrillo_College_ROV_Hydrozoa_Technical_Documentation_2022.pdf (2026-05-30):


## Table of Contents

Abstract | 4
Introduction | 4
Safety | 6
Safety Philosophy | 6
Safety Standards | 6
Safety Features | 6
III. Mechanical Design Rationale | 7
Mechanical Overview | 7
Frame | 8
Electrical Housing | 9
Cameras | 9
Buoyancy and Ballast | 9
Grippers | 10
Pin Extractor | 10
Profiling Float | 10
Material selection and manufacturing | 11
CAD data and BOM | 11
IV. Electrical Design | 12
Overview | 12
Power Distribution | 12
Sensors | 13
Tether | 13
Raspberry Pi | 13
Servos | 13
Cameras | 13
V. Software Design | 14
Overview | 14
Pilot Interface | 15
ROS | 16
Propulsion and Gripper Control | 16

16

VI. Logistics | 16
Company organization | 16
Project management | 17
Budgeting | 18
VIII. Conclusion | 18
A. Testing and Troubleshooting | 18
B. Challenges | 18
C. Lessons Learned and Skills Gained | 19
D. Future Improvements | 19
E. Reflections | 20
IX. Appendix | 21
A. Safety Checklist | 21
B. SID | 22
D. Simplified Task List | 23
E. Budget | 24
F. Sponsors and acknowledgements | 25
G. References | 26

## I. Abstract
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

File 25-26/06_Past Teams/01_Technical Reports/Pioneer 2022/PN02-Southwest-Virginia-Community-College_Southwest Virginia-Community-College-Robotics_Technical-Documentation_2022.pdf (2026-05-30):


# Southwest Virginia Community College Robotics Team

# Technical Documentation – SeaEagle

## MATE Pioneer Class 2022 World Competition

## Members:

Luke Jennelle, President, Safety Officer

Joshua Thiel, CEO, Vice President

Anthony King, Secretary

James Hart, Treasurer (Not pictured)

Kevin Brooks (Not pictured)

Elisabeth Presley


Left to right: Elisabeth Presley, Luke Jennelle, Joshua Thiel, and Anthony King
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

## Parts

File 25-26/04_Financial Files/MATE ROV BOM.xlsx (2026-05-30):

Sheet: TRUE BOM
Predictive Budget | From: 9/01/2025 | To: 5/31/2026
Total Income: | $5100.00
Total Real Expenses | $3412.51 |  | Real in budget | $1687.49
Total Projected Expenses | $5068.66 |  | Projected in budget | $31.34
Income Source | Amount
Source
ThinkTank Grant | $5000.00
BIG Event Donation | $100.00
Expenses
Catagory | Amount Spent | Online cost | Buffer (20%) | Projected Cost | Category | Link | Order ID | Status | Manifest
Total | $3412.51 | $3967.88 | $793.58 | $5068.66 | Team
4 CW Thrusters | $256.00 | $256.00 | $51.20 | $307.20 | F&P | https://www.amazon.com/Underwater-bi-Directional-Waterproof-Photography-Exploration/dp/B09BVKKKTJ | a | Received | Joe Harb | NOTE: make sure each 4 that is purchased are different
4 CWW Thrusters | $256.00 | $256.00 | $51.20 | $307.20 | F&P | https://www.amazon.com/Underwater-bi-Directional-Waterproof-Photography-Exploration/dp/B09BVKB3KD | a | Received | Joe Harb
Peristaltic Pump (Ballast System) | $59.85 | $59.85 | $11.97 | $71.82 | F&P | https://www.amazon.com/Peristaltic-brushless-Adjustable-Liquid-KPHM600/dp/B09PDS7Z51?ref_ | a | Received | Vincent Camarillo
Raspberry Pi 5 8GB | $119.00 | $95.39 | $19.08 | $114.47 | GNC | https://a.co/d/fJQ7PAU | :( | Received
Blue Robotics IMU | $226.50 | $220.00 | $44.00 | $264.00 | GNC | https://bluerobotics.com/store/comm-control-power/control/navigator/ | :( | Received
Pressure sensor | $107.00 | $79.00 | $15.80 | $94.80 | GNC | https://blu-sub.com/products/subsea-depth-sensor-m8 | e | Received
Ultrasonic Sensor | $47.00 | $32.00 | $6.40 | $38.40 | GNC | https://www.dfrobot.com/product-2760.html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 | bb | Received | Andrei Bugayong
ArduCam 4k camera | $60.00 | $60.00 | $12.00 | $72.00 | GNC | https://www.amazon.com/Arducam-Camera-Lightburn-Raspberry-Windows/dp/B0C1G73QZD | :( | Received
BRIO 100 1080p Webcam | $35.06 | $39.99 | $8.00 | $47.99 | GNC | https://a.co/d/0peiM8n | :( | Received
Pico W | $16.31 | $12.00 | $2.40 | $14.40 | GNC | https://www.amazon.com/Pico-Pre-Soldered-Compatible-Microcontroller-Dual-Architecture/dp/B0DP54FWX1 | a | Received | Christopher Gibbs
SPI SD Card Reader | $8.89 | $16.31 | $3.26 | $19.57 | GNC | https://www.amazon.com/Interface-Arduino-Raspberry-Breakout-Cable%EF%BC%88Pack/dp/B07MTTLF75 | a | Received | Christopher Gibbs
Logitech controller | $18.34 | $15.00 | $3.00 | $18.00 | C&C | https://www.amazon.com/Logitech-940-000110-Gamepad-F310/dp/B003VAHYQY/ref=sr_1_1?sr=8-1 | f | Received
Team Registration |  | $550.00 | $110.00 | $660.00 | Team |  |  | Not Ordered
Fluid quiz | $25.00 | $25.00 | $5.00 | $30.00 | Team |  | :) | Received
Vinyl Tubing for Pump | $4.65 | $4.31 | $0.86 | $5.17 | F&P | Ordered in Person | z | Received
IV bag/bladder |  | $20.00 | $4.00 | $24.00 | F&P |  | z | Received
Foam sheet 3/16 in |  | $13.00 | $2.60 | $15.60 | C&C | https://www.zoro.com/zoro-select-foam-sheet-water-resistant-closed-cell-12-in-w-12-in-l-316-in-thick-black-zusansr-303/i/G6758439/ |  | Not Ordered
1 Float Heating Pad |  | $14.29 | $2.86 | $17.15 | TMS | https://www.amazon.com/MECCANIXITY-Silicone-Flexible-Constant-Temperature/dp/B0CLS2KVYM | f | Received
Subsea Buoyancy Foam: R-33012 16 in x 8 in x 1 in | $76.00 | $76.00 | $15.20 | $91.20 | TMS | Subsea Buoyancy Foam (https://bluerobotics.com/store/watertight-enclosures/buoyancy/float-r1/) | b | Received | Alex Huynh
Loctite Marine Epoxy | $16.37 | $10.00 | $2.00 | $12.00 | TMS | https://www.doitbest.com/product/358062/loctite-0-85-oz-marine-epoxy-358062/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 | h | Received
2 Daygreen 48V to 12V 480W DC-DC Step-down Converter | $101.50 | $76.00 | $15.20 | $91.20 | EPS | https://daygreen.com/products/36v-48v-to-12v-40a-480w-dc-dc-step-down-converter-voltage-regulator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 | d | Received
Tenergy NiMH 12V 2000mAh Battery Pack | $39.50 | $36.49 | $7.30 | $43.79 | EPS | https://power.tenergy.com/tenergy-nimh-12v-2000mah-battery-pack-w-bare-leads/ | i | Received | Christopher Gibbs
Manufacturing credits | $247.00 | $155.88 | $31.18 | $187.06 | TMS | https://www.amazon.com/3DHoJor-Update-Filament-Printer-Cardboard/dp/B0F18YDPHM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 | --- | Received
1 400 mm aluminum enclosure, 4 in diameter + $15 tariff | $481.60 | $545.00 | $109.00 | $654.00 | TMS | Locking Tubes for Watertight Subsea Enclosures (https://bluerobotics.com/store/watertight-enclosures/locking-series/wte-locking-tube-r1-vp/) | b | Received | Alex Huynh
4 in diameter aluminum blank cap + $15 tariff (2 caps) | $76.16 | $83.00 | $16.60 | $99.60 | TMS | End Caps and Flange Caps for Subsea Watertight Enclosures (https://bluerobotics.com/store/watertight-enclosures/locking-series/wte-end-cap-vp/) | b | Received | Alex Huynh
O-Ring Flanges 4 in (2 Flanges) + $15 tariff | $112.00 | $115 | $23.00 | $138.00 | TMS | O-ring Flange for Custom Underwater Housings (https://bluerobotics.com/store/watertight-enclosures/locking-series/wte-flange-vp/) | b | Received | Alex Huynh
Servos | $34.03 | $106.00 | $21.20 | $127.20 | TMS | https://www.amazon.com/Waterproof-Coreless-DSSERVO-Stainless-Climbing/dp/B0D4YKK4YQ?hvadid=79989681303546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 | k | Received
1 200 mm acrylic enclosure, 100 mm diameter (Float) | $381.37 | $380.8 | $76.16 | $456.96 | TMS | https://bluerobotics.com/store/watertight-enclosures/wte-vp/ | l | Received | Scott Cripps
1 Zinc disc weight | $18.78 | $8.99 | $1.80 | $10.79 | TMS | https://www.rotometals.com/zinc-disc-3-diameter-x-1-thick/ | m | Received | Alex Huynh
Hinge |  | 5.61 | $1.12 | $6.73 | TMS | https://usstainless.com/deck-hardware/us-stainless-stainless-steel-316-hinge-3-marine-grade/ | n | SOFC form
Flipsky 4-20S Lipo External UBEC 20A 5.0V (default) / 6.0V / 7.4V / 8.4V for RC Car Fixed Wing Aircraft Robot Arm Black | $62.00 | $24.00 | $4.80 | $28.80 | EPS | https://flipsky.net/products/flipsky-4-20s-lipo-external-ubec-20a-5-0v-default-6-0v-7-4v-8-4v-for-rc-car-fixed-wing-aircraft-robot-arm-black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 | o | Received
6061 Aluminum Round Bar 3 1/2 inch diameter 3 inch length | $18.78 | $39.42 | $7.88 | $47.30 | TMS | https://www.coremarkmetals.com/6061-t6511-aluminum-round-bar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 | p | Not Ordered
PCBs | $273.58 | $230.00 | $46.00 | $276.00 | EPS |  | q | Received | Bhavana Shree Pothuri
Littelfuse 25A * |  | $2.81 | $0.56 | $3.37 | EPS | https://www.digikey.com/en/products/detail/littelfuse-inc/0895025.U/F4345-ND/3305707 | u | Not Ordered
Fuse Holder | $14.00 | $14.13 | $2.83 | $16.96 | EPS | https://www.digikey.com/en/products/detail/littelfuse-inc/HLJC1001G/F6110-ND/3427070 | r | Received
SBS50BLU-BK | $14.00 | $4.74 | $0.95 | $5.69 | EPS | https://www.digikey.com/en/products/detail/anderson-power-products-inc/SBS50BLU-BK/10650548 | r | Received
2 x Long Hex Standoff | $39.20 | $4.00 | $0.80 | $4.80 | TMS | Long Hex Standoff (https://bluerobotics.com/store/rov/bluerov2-components-spares/standoff-m3x0-5-212-mf/) | s | Received | Scott Cripps
4x Long Hex Standoff | $39.20 | $4.00 | $0.80 | $4.80 | TMS | Short Hex Standoff (https://bluerobotics.com/store/rov/bluerov2-components-spares/standoff-m3x0-5-31-mf/) | s | Received
2 X Connecters * |  | $3.32 | $0.66 | $3.98 | EPS | https://www.digikey.com/en/products/detail/anderson-power-products-inc/5915-BK/10650335 | u | Not Ordered
Tether (12m) (4 twisted pairs) | $39.20 | $96.00 | $19.20 | $115.20 | EPS | https://bluerobotics.com/store/cables-connectors/cables/fathom-rov-tether-by-the-meter/ | s | Ordered
Bi-directional Logic Level Converter | $13.27 | $4.00 | $0.80 | $4.80 | C&C | https://www.sparkfun.com/sparkfun-logic-level-converter-bi-directional.html | t | Received
Lights | $34.03 | $37 | $7.40 | $44.40 | C&C | https://www.amazon.com/BASIKER-BS1-2x1200LM-Stainless-Underwater/dp/B091Y64V2G | v | Ordered
O-ball | $34.03 | $4.74 | $0.95 | $5.69 | Team | https://www.amazon.com/Bright-Starts-Oball-Easy-Grasp-Classic-Ball-BPA-Free-Age-Newborn/dp/B00ZRD99C0 | v | Received
½-inch PVC base x 10ft |  | $3.98 | $0.80 | $4.78 | Team | https://www.homedepot.com/p/JM-EAGLE-1-2-in-x-10-ft-600-PSI-White-Schedule-40-PVC-Pressure-Plain-End-Pipe-530048/100113200 | w | SOFC form
100ct Chenille Pipe Cleaners |  | $2.99 | $0.60 | $3.59 | Team | https://www.michaels.com/product/primary-chenille-pipe-cleaners-value-pack-100ct-by-creatology-10525295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 | y | Not Ordered
2-inch end cap |  | $1.11 | $0.22 | $1.33 | Team | https://www.pvcfittingsonline.com/collections/sch-40-pvc-caps/products/447-020-2-schedule-40-pvc-cap | aa | Not Ordered
2-inch knockout cap |  | $0.59 | $0.12 | $0.71 | Team | https://www.homedepot.com/p/Oatey-2-in-ABS-Pipe-Test-Cap-with-Knockout-39101D/100137732 | w | SOFC form
2-inch PVC pipe |  | $14.36 | $2.87 | $17.23 | Team | https://www.homedepot.com/p/Charlotte-Pipe-2-in-x-10-ft-White-Schedule-40-PVC-Pipe-Solid-Core-PVC-07200-0600/100348475 | w | SOFC form
Rope |  | $5.26 | $1.05 | $6.31 | Team | https://www.homedepot.com/p/Everbilt-5-32-in-x-75-ft-Neon-Diamond-Braided-Polypropylene-Rope-with-Winder-72846/206094313 | w | SOFC form
Yellow spray paint |  | $6.98 | $1.40 | $8.38 | Team | https://www.homedepot.com/p/Rust-Oleum-Painter-s-Touch-2X-12-oz-Gloss-Sun-Yellow-General-Purpose-Spray-Paint-334046/307244829 | w | SOFC form
1 ½-inch PVC pipe |  | $5.98 | $1.20 | $7.18 | Team | https://www.homedepot.com/p/Charlotte-Pipe-1-1-2-in-x-2-ft-PVC-DWV-Schedule-40-Pipe-PVC071120200HA/100581718 | w | SOFC form
Screw Hook |  | $1.47 | $0.29 | $1.76 | Team | https://www.homedepot.com/p/Everbilt-3-16-in-x-3-3-8-in-Zinc-Screw-Hook-824401/314745390 | w | SOFC form
Corrugated plastic sheeting |  | $34.98 | $7.00 | $41.98 | Team | https://www.homedepot.com/p/Coroplast-48-in-x-96-in-x-0-157-in-4mm-White-Corrugated-Twinwall-Plastic-Sheet-CP4896S/205351385 | w | SOFC form
Cable Wire | $74.66 | $8.99 | $1.80 | $10.79 | Team | https://www.amazon.com/Conductor-Electrical-Stranded-Extension-Automotive/dp/B0CN76L8G3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 | v | Ordered
Heat-Set Threaded Inserts (100 pc) | $10.39 | $9.99 | $2.00 | $11.99 | F&P | https://www.amazon.com/HANGLIFE-Heat-Set-Threaded-Printing-Components/dp/B0CS6XGMFD?s=industrial | cc | Received
Heat-Set Threaded Inserts (100 pc) | $10.39 | $9.99 | $2.00 | $11.99 | F&P | https://www.amazon.com/Fgruh-Washers-Assortment-Stainless-Printer/dp/B0FG2D92BV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 |  | Received
Power Cable (50 ft) |  | $54.00 | $10.80 | $64.80 | EPS | https://www.amazon.com/Oxygen-Free-Insulated-Electrical-Automotive-Trailer/dp/B0B6HV5TXQ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 |  | Received
12V to 5V Converter (Float) |  | $8.00 | $1.60 | $9.60 | EPS | https://www.amazon.com/LM2596-Converter-3-0-40V-1-5-35V-Supply/dp/B08NV3JCBC?th=1 |  | Not Ordered
5V Block |  | $13.99 | $2.80 | $16.79 | EPS | https://www.amazon.com/ANMBEST-Terminal-Mounting-Distribution-Amplifier/dp/B0C7PYCZZ4?nsdOptOutParam=true |  | Not Ordered
UCB C | $9.60 | $8.99 | $1.80 | $10.79 | EPS | https://www.amazon.com/11inch-Pigtail-Equipment-Installed-Replacement/dp/B0DLKPWF1G |  | Received
Wagos | $16.27 | $14.99 | $3.00 | $17.99 | EPS | https://www.amazon.com/Connectors-Avarbuvo-Electrical-Splice-Terminals/dp/B0D8731XH4 |  | Received
Wire |  | $13.99 | $2.80 | $16.79 | EPS | https://www.amazon.com/VIABRICO-Extension-Lights-Voltage-Connectors/dp/B0B49TQZHV?s=industrial |  | SOFC form
12V Blocks |  | $16.99 | $3.40 | $20.39 | EPS | https://www.amazon.com/risingsaplings-Position-Terminal-Distribution-Module/dp/B0DBW6XH66?s=industrial |  | Not Ordered
Raspberry Pi 5 Active Cooler |  | $9.89 | $1.98 | $11.87 | GNC | https://www.amazon.com/Raspberry-Pi-Active-Cooler/dp/B0CLXZBR5P?s=electronics |  | Not Ordered
M6 Heated Inserts | $11.49 | $12.44 | $2.49 | $14.93 | TMS | https://www.walmart.com/ip/26-Pcs-Threaded-Inserts-M6-Brass-Heat-Set-Insert-for-3D-Printing-M6x8x5mm/15698402213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 |  | Received
Flexible Epoxy Potting | $121.09 | $120.13 | $24.03 | $144.16 | TMS | MG Chemicals 832FX-450ML Epoxy Encapsulating and Potting Compound 450ML (15.2 fl oz) Bottle (https://us.rs-online.com/product/mg-chemicals/832fx-450ml/71033671/?keyword=832FX-450ML) |  | Received
2x SS Clamp | $4.06 | $3.76 | $0.75 | $4.51 | F&P | Ordered in person |  | Received
1 Lighter | $5.37 | $4.97 | $0.99 | $5.96 | F&P | Ordered in person |  | Received

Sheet: Worlds travel budget
# of people | 4 |  |  | Total
 |  |  |  | $6342.80
Item | Units | Cost per unit | Cost per unit + 20% | Total cost + buffer | Link | Notes
 | 1 Flight per person
Flight DFW to YYT | 4 | $843.00 | $1011.60 | $4046.40 | https://www.expedia.com/Flight-Information?marketingChannel=DIRECT | Standard fare, saved on checking bags by choosing carry-on
 | x guys for 5 nights with 4 guys to a room
Guys Hotel Room | 2.5 | $231.00 | $277.20 | $693.00 | https://www.expedia.com/St-Johns-Hotels-Sheraton-Hotel-Newfoundland.h25025.Hotel-Information?chkin=2026-06-23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 | Chose more expensive hotel to save on not needing a rental car
 | x girls for 5 nights with 4 girls to a room
Girls Hotel Room | 2.5 | $231.00 | $277.20 | $693.00 | https://www.expedia.com/St-Johns-Hotels-Sheraton-Hotel-Newfoundland.h25025.Hotel-Information?chkin=2026-06-23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 | Chose more expensive hotel to save on not needing a rental car
 | 1 car per person for 5 days
Parking | 20 | $15.00 | $18.00 | $360.00 | https://www.theparkingspot.com/reserve
 | 6 to meet minimum order
Team Uniforms | 6 | $50.00 | $60.00 | $360.00 | https://www.customink.com/ndx/?PK=945107&SK=945100&prefer_singles=false#/next/summary
 | Average milage to DFW * Number of people | Cost/Mile
Gas | 840 | $0.19 | $0.23 | $190.40

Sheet: Early bom
Part name | # | Specs | Quantity | Cost | Justification | Link | Supplier | Total Cost | Notes
XLamp® XHP70.2 LEDs (https://downloads.cree-led.com/files/ds/x/XLamp-MKR.pdf) | 2 | Lighting system | 2 | $14.72 | Efficient at dissipating heat, view angle of 120 degrees, high tolerance to heat, compact, similar lighting system that previous teams used but newer model | here (https://www.digikey.com/en/products/detail/cree-led/MKRAWT-00-0000-0D00J2051/21841944) | DigiKey | $29.44
Arduino | 1 | Starting Kit | 1 | $84.75 | Building, testing, and operation of various circuits and breadboards | http://tinkersphere.com/boards/1443-ardx-arduino-kit-nyc.html?gQT=3 | Tinkersphere | $84.75
Wiring | 250ft | 14/2 wire | 2 | $104.00 | Wiring the electrical components of the submersible | https://www.homedepot.com/p/Southwire-250-ft-14-2-Romex-SIMpull-Solid-NM-B-W-G-Wire-28827469/202019377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 | Home Depot | $208.00
Adafruit 9-DOF Absolute Orientation IMU Fusion Breakout - BNO055 | 1 | IMU | 1 | $34.05 | Checks Orientation of ROV | https://www.adafruit.com/product/2472? | Adafruit | $34.05
MS5803-07BA High Resolution 24-Bit Altimeter and Temperature Sensor ±.8°C I2C Mini Module | 1 | Pressure/Temperature Sensor | 2 | $70.95 | Detects the temperature and pressure, which allows for the calculation of depth and can monitor the system's health | https://store.ncd.io/product/ms5803-07ba-high-resolution-24-bit-altimeter-and-temperature-sensor-%c2%b1-8c-i2c-mini-module/ | NCD | $141.90
SOS Leak Sensor | 1 | Leak sensor | 3 | $35.00 | detect water leaking into an improperly sealed Watertight Enclosure, preventing major dmg | https://bluerobotics.com/store/sensors-cameras/leak-sensor/sos-leak-sensor/ | Blue Robotics | $105.00
3D Printing Filament PETG | 1 | Filament | 27 | $14.99 | Creating units to house parts, 100% Infill (Cost is based on previous teams spending) | https://www.amazon.com/Filament-Printer-Printing-Materials-CC3D/dp/B09B4XFJQ99 | Amazon | $404.73
Low Light Camera | 1 | Low light, USB | 2 | $35.00 | For sensing obstructions and mapping the aquious environment | https://www.waveshare.com/ov2710-2mp-usb-camera-a.htm | Waveshare | $70.00
PS5 Controllers | 1 | Controller | 2 | $74.00 | Controls the ROV | https://www.amazon.com/PlayStation-DualSense%C2%AE-Wireless-Controller-Midnight-5/dp/B0CQKKHT5J | Amazon | $148.00
Raspberry PI | 2 | Electrical | 1 | $14.00 | Controlling and handling signals between subsystems of the submersible | https://www.amazon.com/Raspberry-Pi-Pico-RP2040-microcontroller/dp/B092S2KCV2?gQT=1 | Amazon | $14.00
Thermal paste | 1 | Miscellaneous | 2 | $6.99 | To help with cooling | https://www.amazon.com/ARCTIC-MX-4-2019-Performance-Durability/dp/B07L9BDY3T | Amazon | $13.98
Gallon Bins | 1 | Miscellaneous | 5 | $4.98 | To store everything | https://www.walmart.com/ip/Sterilite-Medium-Tote-Plastic-Adult-Blue-Ash/9406368583?wmlspartner=wlpa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 | Walmart | $24.90
HDPE | 2 | Frame | 3 | $127.25 | 1/4" Black HDPE 48" x 96" for a lightweight and stable robot | https://shapesplastics.com/hdpe-1-4-black-48-x96 | SHAPES Plastics | $381.75
Polycarbonate | 1 | Electronic Housing | 3 | $53.00 | Transparent housing that is durable and lightweight | https://www.amazon.com/Polycarbonate-Lexan-Sheet-Clear-0-250/dp/B07KCYC7K7 | Amazon | $159.00
T200 Thruster | 1 | Propulsion | 4 | $258.00 | Increase number of thrusters for a better control of the rov | https://bluerobotics.com/store/thrusters/t100-t200-thrusters/t200-thruster-r2-rp/ | Blue Robotics | $1032.00
Manipulator Air Pneumatic Gripper Clamp | 1 | Pneumatics | 1 | $201.00 | Rov will need to interact with surroundings in order to score more points. Great gripping force will be needed | https://www.amazon.com/XUNCHAO-Manipulator-Pneumatic-Automation-Scissors/dp/B0D7W1Z19F?th=1 | Amazon | $201.00
Loctite Marine Epoxy | 1 | Waterproof Testing | 3 | $10.00 | Sealing and waterproofing | https://bluerobotics.com/store/cables-connectors/tools/loctite-marine-epoxy/ | Blue Robotics | $30.00
Watertight Enclosure Spare O-Ring Set | 3 | Waterproof Testing | 2 | $3.00 | Sealing and waterproofing (Dimensions are an estimation) | https://bluerobotics.com/store/watertight-enclosures/locking-series/spare-o-ring-set/ | Blue Robotics | $6.00
Buoyancy foam | 1 | Buoyancy | 1 | $114.99 | To achieve neutral buoyancy | https://www.amazon.com/TotalBoat-Urethane-Density-Flotation-Reinforcement/dp/B01AAWRYZG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 | Amazon | $114.99
Pelican case | 1 | Miscellaneous | 1 | $49.95 | Good for keeping electronics safe | https://www.amazon.com/Pelican-1120-Case-Foam-Black/dp/B0051QIBUE?mcid=b0e3acc88fcf3e8ba43fcfa39289f819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 | Amazon | $49.95
Sanuke 1100gph Bilge Pump | 1 | Propulsion | 5 | $14.98 | Multiple uses: Water sampling system, gripper, thruster replacement, possible ballast pumps | https://www.amazon.com/dp/B07VKMTC9J?previewDoh=1 | Amazon | $74.90
WetLink Cable Splice Kit | 1 | Tether | 2 | $20.00 | To create waterproof, high-pressure cable connections | https://bluerobotics.com/store/cables-connectors/tools/wlp-splice-kit/ | Blue Robotics | $40.00
WetLink Penetrator | 1 | Tether | 2 | $16.00 | Necessary for the usage of WetLink Cable Splice Kit | https://bluerobotics.com/store/cables-connectors/penetrators/wlp-vp/ | Blue Robotics | $32.00
Fasteners | 1 | Frame | 2 | $40.00 | bolt and nut sets, washers, etc (Cost is an estimation) | - | Amazon | $80.00
Waterproof Electrical Connectors | 1 | Electrical | 1 | $39.99 | Extra waterproof connectors | https://www.amazon.com/Twippo-Waterproof-Automotive-Electrical-Connectors/dp/B0CBJV2WSM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 | Amazon | $39.99
Zip ties | 1 | Miscellaneous | 2 | $18.99 | Cable management | https://www.amazon.com/HS-Durable-Plastic-Bulk-1000-Self-Locking/dp/B07WRY1HM4?sp_csd=d2lkZ2V0TmFtZT1zcF9hdGY | Amazon | $37.98
Heat shrink Tubing | 1 | Electrical | 1 | $6.59 | Cable management | https://www.amazon.com/Shrink-Tubing-Industrial-Heat-Shrink-Wires/dp/B0BG6V4HV4?gQT=1 | Amazon | $6.59
Air Compressor | 1 | Pneumatics | 1 | $53.99 | Supply air to the system (follows mate rov's guidelines) (http://amazon.com/MCIGCIM-200pcs-Connectors-Insulated-Terminals/dp/B07Z7LTNR5) | https://www.amazon.com/AstroAI-Compressor-Light%EF%BC%8CAutomotive-Accessories-mattresses/dp/B0C1GL5T7G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 | Amazon | $53.99
Pneumatic Valves | 1 | Pneumatics | 2 | $26.99 | To control Air flow | https://www.amazon.com/BLCH-PNEUMATIC-Solenoid-Pilot-Operated-Connection/dp/B0DHPL43L7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 | Amazon | $53.98
Pneumatic Cylinder | 1 | Pneumatics | 2 | $159.99 | Used for linear motion | https://www.amazon.com/Baomain-Pneumatic-Cylinder-SC-63-700/dp/B07ZS7NY3N?utm_source=chatgpt.com | Amazon | $319.98
Pressure Relief Valve | 1 | Pressure Relief | 3 | $30.00 | Relief pressure in housing | https://bluerobotics.com/store/watertight-enclosures/enclosure-tools-supplies/prv-m10-asm/ | Blue Robotics | $90.00
Power Sense Monitor | 1 | PSM | 1 | $92.00 | Monitors power output and current battery level | https://bluerobotics.com/learn/power-sense-module-psm-installation/ | Blue Robotics | $92.00
Johnson Pumps 05503-00 12V 500 GPH | 1 | Thruster | 1 | $68.99 | Extra Thruster incase of test failure | https://www.amazon.com/Johnson-Pump-Cartridge-Combo-550GPH/dp/B005BTAVD6?adgrpid=1341405801776282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 | Amazon | $68.99
Waterproof Heat Shrink Electrical Connectors | 1 | Electrical | 1 | $7.99 | connects electrical cables and waterproofs them | https://www.amazon.com/Kuject-Connectors-Waterproof-Electrical-Automotive/dp/B073RMRCC3 | Amazon | $7.99
PU Tubing | 1 | Pneumatics | 2 | $23.99 | For connecting pneumatic components | https://www.amazon.com/PneumaticPlus-4-Inch-Tubing-100Foot-Compressor/dp/B00B04UAIC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 | Amazon | $47.98
Pressure Regulator | 1 | Pneumatics | 1 | $22.03 | To protect our components. Safety measure | https://www.amazon.com/SNS-AR2000-N02-Pressure-Regulator-Adjustable/dp/B0895G3FZ3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 | Amazon | $22.03
Waterproof labels | 1 | Electrical | 4 | $14.99 | Cable management and easy troubleshooting, also for organizing station | https://www.amazon.com/Premium-Label-Supply-Waterproof-Address/dp/B0DNGCYVPF?sp_csd=d2lkZ2V0TmFtZT1zcF9hdGY | Amazon | $59.96
Silicon Grease | 1 | Miscellaneous | 1 | $7.99 | Lubricating seals and O rings | https://www.amazon.com/Waterproof-Silicone-Lubricant-Plumbers-Sealant/dp/B0BN82TPY4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 | Amazon | $7.99
Solenoid | 1 | Pneumatics | 2 | $9.99 | Switches for the control airflow | https://www.amazon.com/Beduan-Normally-Closed-Electric-Solenoid/dp/B07N2DZ5FP | Amazon | $19.98
Elbow fitting | 2 | Pneumatics | 2 | $7.59 | Joining pneumatic components | https://www.amazon.com/Degree-Barstock-Fitting-CX-WONDERLAND/dp/B0BCZFCFQ7?sp_csd=d2lkZ2V0TmFtZT1zcF9hdGY | Amazon | $15.18
Tee Fittings | 2 | Pneumatics | 3 | $7.49 | Joining pneumatic components | https://www.amazon.com/Joywayus-Fittings-T-Shaped-Fitting-Stainless/dp/B082KRLRM7 | Amazon | $22.47
Straight Connector | 10 | Pneumatics | 2 | $10.49 | Joining pneumatic components | https://www.amazon.com/PneumaticPlus-PUC-1-Connect-Fitting-Straight/dp/B01N8P0NV4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 | Amazon | $20.98
Desiccant packets | 15 | Miscellaneous | 2 | $5.99 | Waterproof and Safety | https://www.amazon.com/Transparent-Desiccant-Packets-Moisture-Electronics/dp/B09DSDX4P3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 | Amazon | $11.98
Flexible Conduit | 1 | Electrical | 1 | $79.99 | Safety measure to keep cables protected | https://www.amazon.com/Elecoman-Liquid-Tight-Connector-Electrical-90-Degree/dp/B0CGR33PJF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 | Amazon | $79.99
Camera mount | 24 | Camera | 1 | $18.99 | To stabilize camera | https://www.amazon.com/Adapter-Converter-Monopod-Ballhead-Frgyee/dp/B0956Z9MX5?cv_ct_cx=Camera%2Bmounts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 | Amazon | $18.99
Toolbox organizer | 1 | Miscellaneous | 2 | $20.99 | Sorting fasteners and other components | https://www.amazon.com/LUGEI%E3%80%90%F0%9D%9F%B0%F0%9D%9F%B2%F0%9D%97%A3%F0%9D%97%96%F0%9D%97%A6%E3%80%91%E3%80%905-Organizer-Organization-Accessories-WorkBe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 | Amazon | $41.98
ETX30LA AGM Sea Mate Universal Fit | 1 | Power Supply | 3 | $227.02 | Kits do not include batteries | https://www.ebay.com/itm/124159993906 | Ebay | $681.06
Buck Converters | 2 | Electrical | 2 | $14.99 | For any sensor or other low power electronic | https://www.amazon.com/Converter-Voltage-Regulator-Supply-Waterproof/dp/B0DQKFZ2BF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 | Amazon | $29.98
Battery Monitoring | 1 | Power Supply | 1 | $175.00 | Monitors voltage and current | https://www.bluebgi.com/products/p/smart-skipper-battery-mate-bgws-02 | Blue Guard | $175.00
Hydraulics Kit | 1 |  | 1 | $68.99 | Provided through previous funds | https://seamate.org/products/hydraulics-kit?variant=32763610300487 | Sea MATE | $68.99
Powerwerx TRIcrimp Powerpole Connector | 1 |  | 2 | $45.00 | Provided through previous funds | https://seamate.org/products/powerwerx-tricrimp-powerpole-connector | Sea MATE | $90.00
Barracuda ROV with Thrusters and Tether (Rev 2) | 1 |  | 1 | $1260.00 | Provided through previous funds | https://seamate.org/products/barracuda-rov-kit-with-thrusters-and-tether | Sea MATE | $1260.00
TriggerFish/Barracuda Video System | 1 |  | 1 | $210.00 | Provided through previous funds | https://seamate.org/products/triggerfish-barracuda-video-system-kit?variant=41395478560839 | Sea MATE | $210.00
Powerwerx 12V DC Power Supply w Powerpole outlet + GFCI | 1 |  | 1 | $230.00 | Provided through previous funds | https://seamate.org/products/powerwerx-12v-dc-power-supply-w-powerpole-outlet-gfci | Sea MATE | $230.00
3D printing time Cost per hour | 1 |  | 30 | $3.00 | Utilization of Filament to create and house parts | - | - | $90.00
Entry Fees | 1 |  |  | $200.00 |  |  |  | $200.00
 |  |  |  |  |  |  |  | $7656.37
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

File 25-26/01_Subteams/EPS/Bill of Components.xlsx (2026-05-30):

Components needed according to MATE ROV: | Cost | Quantity | Type
Littelfuse |  |  | R
Anderson SBS50 Connector |  |  | R
Printed Circuit Boards (Power Conversion, Front-End, Control Board) |  | 2 | R
Water-proof Wiring |  |  | R+F
48V to 12V transformer |  | 1 | R
12V to 5V transformer |  | 2 | R+F
5V to 3.3V transformer |  | 2 | R+F
Nickel Metal Hydride Battery Pack | $11 to $40 | 1 | F
5A Fuse | $5 | 1 | F
Solderable Breadboard |  | 1 | R

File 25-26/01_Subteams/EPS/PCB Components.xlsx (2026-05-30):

Line # | Original Part Number | Description | Part Number (Cheapest/Best Match) | Specs & Notes | Link To Purchase
1 | 691412220008 | 2-Pin Terminal Block | DG128-5.0-02P-14-00A(H) | This is a 2-pin header, however, you can use 4 of them together | https://jlcpcb.com/partdetail/DEGSON-DG128_5_0_02P_14_00A_H/C711349
2 | GRM188R61A106KE69D | 10uF 10V 0603 X5R | C19702 (CL10A106KP8NNNC) | Standard 0603 Capacitor. | https://jlcpcb.com/parts/componentSearch?searchTxt=C19702
3 | 0603B104K500CT | 0.1uF 50V 0603 X7R | C14663 (0603B104K500NT) | Standard 0603 Capacitor. | https://jlcpcb.com/parts/componentSearch?searchTxt=C14663
4 | 1714955 | Power Input Terminal | (DG128-5.0-02P-14) | 32A Rated. Use two in parallel for 50A. | https://jlcpcb.com/partdetail/DEGSON-DG128_5_0_02P_14_00A_H/C711349
5 | MCT06030D5101BP500 | 100 ohm 0603 Resistor | C22775 (0603WAF1000T5E) | 1% Tolerance, 1/10W. | https://jlcpcb.com/parts/componentSearch?searchTxt=C22775
6 | USB4145-03-0230-C | USB-C 16-Pin SMT | C2988358 | Alternative for design since original is out of stock | https://jlcpcb.com/parts/componentSearch?searchTxt=C2988358
Things we might want to add:
Part Category | Recommended Part Number | Part Number | Qty | Reason for Addition | Link To Purchase
USB-C Logic | 5.1k ohm 0603 Resistor | C23186 | 2 | Enables USB-C Power Delivery for onboard computers/sensors. | https://jlcpcb.com/parts/componentSearch?searchTxt=C23186
Bulk Capacitor | 1000uF 25V Electrolytic | C157973 | 2026-01-02 | Prevents voltage "sags" when 50A load spikes. | https://jlcpcb.com/parts/componentSearch?searchTxt=C157973
Circuit Protection | Blade Fuse Holder (SMT/THT) | C2902047 | 2026-01-04 | Protects traces from melting during a short circuit. | https://jlcpcb.com/parts/componentSearch?searchTxt=C2902047
High Current Input | M5 Screw Terminal (Bolt) | Can't find any in time | 2 | Bolt-down terminals are much more vibration-resistant than spring/screw clips.
Mounting Hardware | M3 Brass Standoffs (10mm) | Can't find any in time | 4 | Required to keep the high-power board safely off surfaces.

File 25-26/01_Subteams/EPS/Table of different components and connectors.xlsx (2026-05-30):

Subsystem | Component | Manufacturer | Part Number | Function | Connector / Mounting | Voltage / Current Rating | Est. Cost
Main Power Protection | High Current Fuse | Littelfuse | 0298080.ZXEH | Primary Safety: Protects the system from catastrophic shorts. | Bolt-On (M8/M6) | 32V / 80A | $7.46
Main Power Input | High Current Connector | Anderson | SB50 6331G1 | Tether Interface: Main quick-disconnect for the battery or surface power. | SB-Series Plug | 600V / 50A | $20.00
48V to 12V Conversion | High Power DC-DC | Daygreen | DE4D1240W | Motor Power: Steps down 48V tether power to 12V for thrusters. | Flying Leads | Input 36-72V / Output 12V 40A | $38.00
12V to 5V Logic | High Power DC-DC | Flipsky | UBEC 20S 20A | Sensor and Servo Power: Steps down 48v tether power to 5v for pi and sensors. | Raw Wire Leads | Input 15V to 84V / Output 5V 20A | $24.00
Servo Power | UBEC Module | Hobbywing | UBEC 10A V2 | Actuators: Steady supply for robotic claws or camera gimbals. | Servo Plug / Solder | Input 7-25.2V / Output 10A (20A burst) | $27.00
3.3V Regulation | Step-down Regulator | Texas Instruments | TPS62172 | Sensor Power: High-efficiency buck regulator for microcontrollers and IMUs. | SMT (WSON-8) | Input 3-17V / Output 3.3V 0.5A | $2.00
Surge Protection | TVS Diode | Littelfuse | SMBJ58A | Spike Protection: Clamps voltage surges caused by thrusters or long cables. | SMT (SMB) | 58V Standoff / 93.6V Clamp | $0.45
Reverse Polarity | MOSFET Protection | Infineon | BSC009NE2LS5 | Circuit Safety: Prevents damage if the power is plugged in backward. | SMT (TDSON-8) | 25V / 100A (Continuous) | $2.20
Current Monitoring | Power Monitor | Texas Instruments | INA226 | Telemetry: Reports real-time voltage and current usage to the pilot. | SMT (VSSOP-10) | 0-36V Bus Voltage / 10uV Offset | $3.00
Bulk Capacitance | Low ESR Capacitor | Panasonic | EEH-ZK1V471P | Energy Buffer: Stabilizes power rails during sudden thruster bursts. | SMT (V-Chip) | 35V / 470uF (3.3A Ripple) | $3.50
Thermal Monitoring | Temp Sensor | Texas Instruments | TMP102 | Internal Health: Monitors internal hull temperature for overheating. | SMT (SOT-563) | 1.4 to 3.6V Supply | $1.15
Logic Connectors | Board Connectors | JST | JST-PH Series | Internal Wiring: Secure, vibration-resistant connections for low-power sensors. | 2.0mm Header | 100V / 2.0A | $0.35
High Current Output | Power Connector | Amass | XT30 | Auxiliary Power: Distributes 12V power to external lights or tools. | 2mm Bullet / Solder | 500V / 30A (Continuous) | $1.25
EMI Filtering | Ferrite Bead | Murata | BLM31 | Noise Filter: Suppresses high-frequency interference from power converters. | SMT (1206) | ~30V / 1.5A to 6A | $0.50

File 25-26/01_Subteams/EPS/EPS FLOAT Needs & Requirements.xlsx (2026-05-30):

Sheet: Needs
Need ID | Need Statement | Priority | Rationale | Source / Reference
N1 | Provide reliable onboard power for all float systems, including buoyancy engine, communication module, and sensors. | High | Power stability ensures that the float can complete full mission profiles without loss of function. | MATE 2026 Rules – ELEC-NRD-001
N2 | Ensure electrical system safety via fusing and current protection. | High | Prevents electrical fires or damage to components if short circuits or overcurrent conditions occur. | ELEC-NRD-004
N3 | Use approved battery chemistries per competition rules (NiMH or AGM only). | High | Complies with MATE safety standards and prevents use of high-risk LiPo batteries. | ELEC-NRD-003
N4 | Maintain continuous power under cold and pressurized conditions (simulated under-ice). | Medium | The float must function reliably in extreme conditions without voltage drop or system reset. | Mission Conditions
N5 | Provide sufficient energy capacity to complete two full vertical profiles and post-mission transmission. | High | Ensures all mission tasks are completed before power depletion. | Mission Task Description
N6 | Allow for easy fuse inspection and replacement during setup or inspection. | Medium | Quick inspection reduces downtime and ensures compliance with visual safety checks. | ELEC-NRD-004
N7 | Minimize system mass and volume to meet float size limits (<1 m length, <18 cm diameter). | Medium | Prevents interference with buoyancy control and ensures compliance with dimensional limits. | Float Specifications
N8 | Provide documentation showing full load current measurements and fuse sizing. | High | Confirms correct fuse and power design for safe operation. | DOC-004 Requirement
N9 | Include power distribution schematic with labeled connections and safety features. | Medium | Provides clarity for inspection and ensures safe wiring layout. | DOC-004 SID Requirement

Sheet: Requirements
Req ID | Requirement Statement | Verification Method | Related Need(s) | Priority | Rationale | Reference
R1 | The EPS shall supply 12 VDC maximum at ≤5 A to all systems. | Test/Inspection | N1 | High | Ensures the system meets non-ROV electrical limits and safely powers all components. | ELEC-NRD-001
R2 | The EPS shall include a single fuse within 5 cm of the positive battery terminal. | Inspection | N2 | High | Guarantees that all current passes through one protection point, preventing unsafe bypasses. | ELEC-NRD-004
R3 | All onboard batteries shall be NiMH or AGM type; no LiPo or alkaline batteries allowed. | Inspection | N3 | High | Ensures battery safety and compliance with chemical and current limits. | ELEC-NRD-003
R4 | The fuse rating shall match the measured full-load current of the system, rounded up to the nearest available standard size. | Test/Analysis | N2, N8 | High | Prevents under- or over-fusing while ensuring current protection matches system draw. | ELEC-NRD-005
R5 | EPS components shall operate for at least 10 minutes in ambient temperatures down to -10 °C. | Environmental Test | N4 | Medium | Confirms system resilience under simulated under-ice mission conditions. | Mission Conditions
R6 | The battery pack and fuse shall be visible or accessible for visual amperage verification. | Inspection | N6 | Medium | Facilitates inspection and ensures fuse ratings can be confirmed on-site. | ELEC-NRD-004
R7 | The entire EPS assembly (battery, housing, wiring) shall fit within the float’s <1 m total length and <18 cm diameter envelope. | Measurement | N7 | Medium | Ensures compliance with float dimensional limits and weight constraints. | Float Specifications
R8 | The EPS documentation shall include measured full-load current (idle and active) and fuse size justification. | Documentation Review | N8 | High | Confirms proper power sizing and safety for system approval. | DOC-004
R9 | The SID shall show standard fuse symbol, wiring, and measured current values. | Documentation Review | N9 | Medium | Provides traceable electrical documentation for verification and compliance. | DOC-004 SID

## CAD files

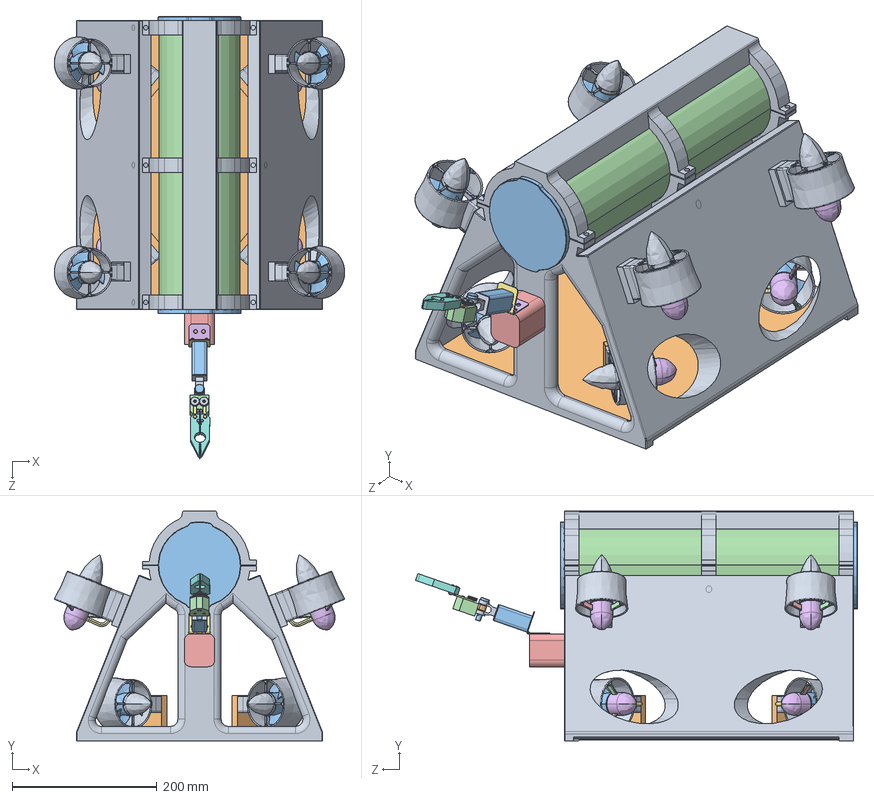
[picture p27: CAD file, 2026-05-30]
25-26/01_Subteams/TMS/TMS 25-26/TMS Prototyping/TMS CAD 2025/Simulations/Final Assembly (20 20 26) (Processed for Simulation).STEP
401.8 x 317.7 x 611.4 mm
Chassis Prototype (400 mm fixed)
Bassplate
Diamond Thruster Guard (Manufacturer''s Shroud) x 8
Flange 4in diameter (1) x 2
4in aluminum blank end cap x 2
400 mm aluminum tube
Arm 1 FIXED
HINGE PART 1
Hinge PART 2
Bar
SHORTY LOL
OKAYYY PART 2
OKAYYYY 3
plate for claw
Thingy for top part of plate x 2
plug x 4
Bar 2 x 2
Part of Claw x 2
gear x 2
plug 2 x 2

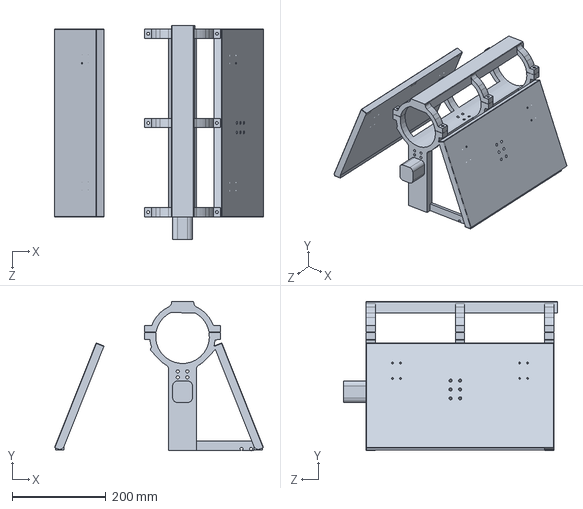
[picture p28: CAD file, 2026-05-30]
25-26/01_Subteams/TMS/TMS 25-26/TMS Prototyping/TMS CAD 2025/Final Assembly, exploded view, Tabs, upper enclosure.SLDPRT
445.3 x 317.7 x 455.3 mm

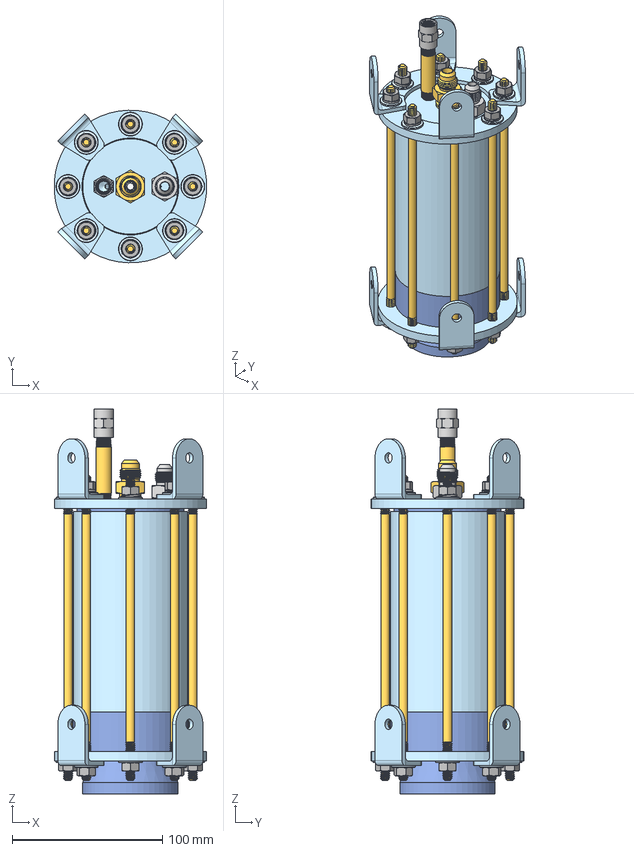
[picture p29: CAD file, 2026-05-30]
25-26/01_Subteams/TMS/TMS 25-26/TMS Prototyping/TMS CAD 2025/[TCA Assembly].step
101.5 x 101.6 x 256.3 mm
90281A102_Black-Oxide Steel Threaded on Both Ends Setup Stud x 8
95505A601_Medium-Strength Steel Hex Nut x 16
Bracket, Thrust Chamber Mounting x 8
92141A029_18-8 Stainless Steel Washer x 16
Throat Insert, Spring Retained
91102A750_Zinc-Plated Steel Split Lock Washer x 8
Combustion Chamber
Flange Plate, Thrust Chamber x 2
94095K114_High-Temperature Graphite Gasket
Nozzle, for Throat Insert
9396K79_High-Temperature Silicone O-Rings x 2
50785K171_High-Pressure Brass Pipe Fitting
50785K91_High-Pressure Brass Pipe Fitting
90015A410_18-8 Stainless Steel Oversized Truss Head Slotted Screw
Injector, Basic Orifice Pattern
9368T14_High-Temperature Dry-Running 841 Bronze Sleeve Bearing
90213A101_Inverted External Retaining Ring
50675K164_37 Degree Flared Fitting for Copper Tubing
50675K435_37 Degree Flared Fitting for Copper Tubing

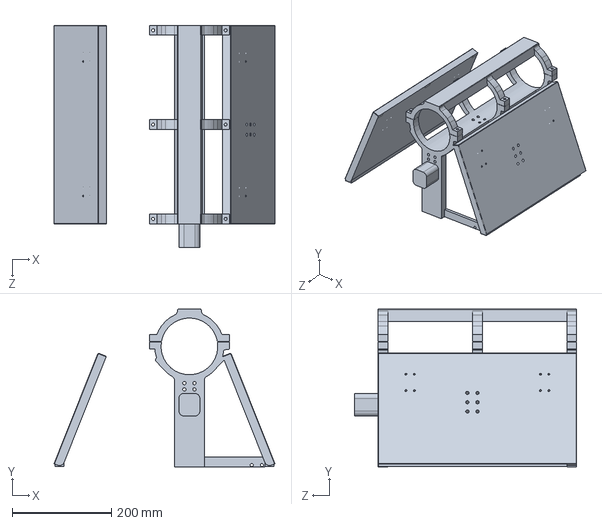
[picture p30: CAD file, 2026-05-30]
25-26/01_Subteams/TMS/TMS 25-26/TMS Prototyping/Final Assembly, exploded view, Tabs, upper enclosure.SLDPRT
445.3 x 317.7 x 448.0 mm

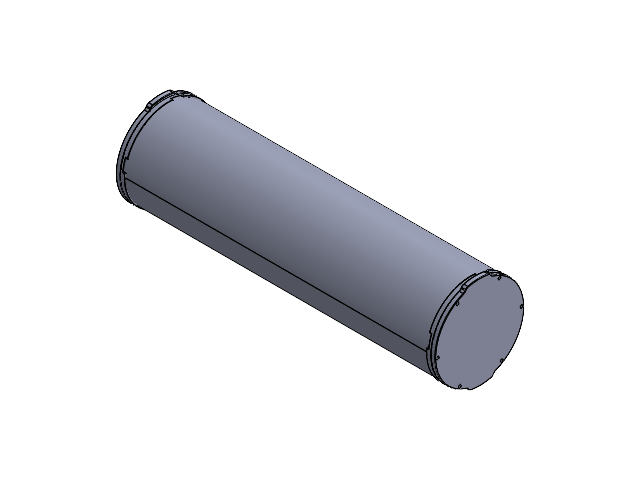
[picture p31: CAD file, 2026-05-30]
25-26/01_Subteams/TMS/TMS 25-26/TMS Prototyping/TMS CAD 2025/Final Assembly (20 20 26)/Final Assembly (20 20 26) (Unzipped Files)/400 mm aluminum assembly.SLDASM
Flange 4in diameter (1) x 2
4in aluminum blank end cap x 2
400 mm aluminum tube

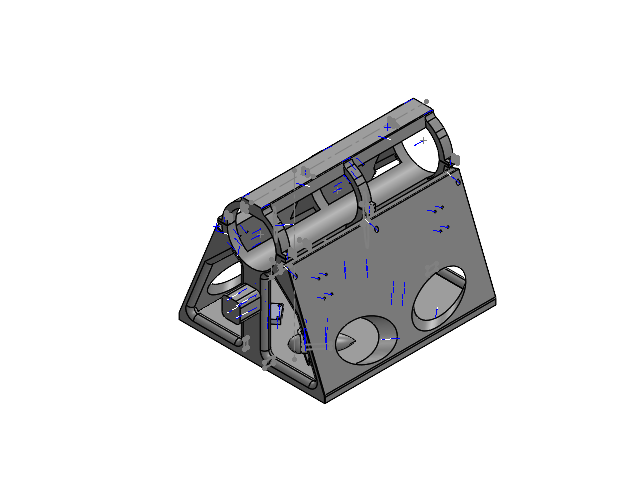
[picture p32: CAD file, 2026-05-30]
25-26/01_Subteams/TMS/TMS 25-26/TMS Prototyping/Assembly slicer (Slice for Chassis, with arm 1 included with chassis component).SLDASM
Chassis Prototype (400 mm fixed) (for slice)
Bassplate (3)
Diamond Thruster Guard (Manufacturer's Shroud)
Horizontal Mount (1)
Horizontal Mount Platform x 4

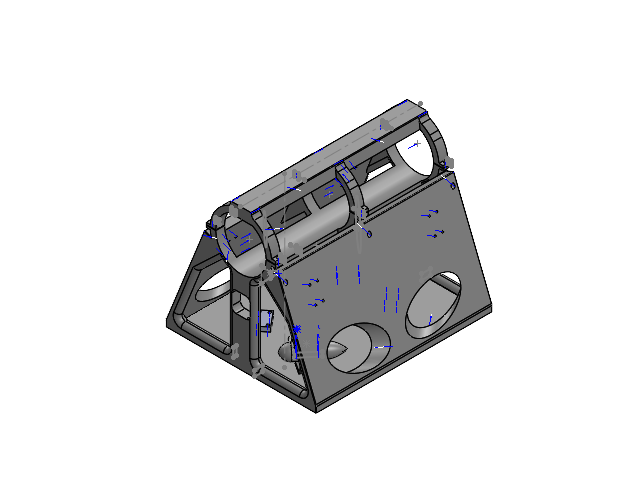
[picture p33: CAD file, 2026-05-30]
25-26/01_Subteams/TMS/TMS 25-26/TMS Prototyping/Assembly slicer (Slice for Chassis, disregard thruster, and baseplate with horizontal platforms).SLDASM
Chassis Prototype (400 mm fixed) (for slice)
Bassplate (3)
Diamond Thruster Guard (Manufacturer's Shroud)
Horizontal Mount (1)
Horizontal Mount Platform x 4

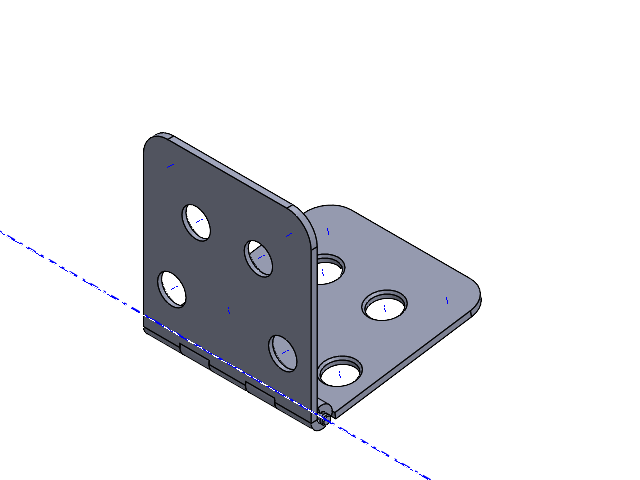
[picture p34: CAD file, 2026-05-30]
25-26/01_Subteams/TMS/TMS 25-26/TMS Prototyping/TMS CAD 2025/Prototype1 Chassis/Scary Chassis Creations/Hinge Assembled 2.SLDASM
HINGE PART 1
Hinge PART 2
Bar

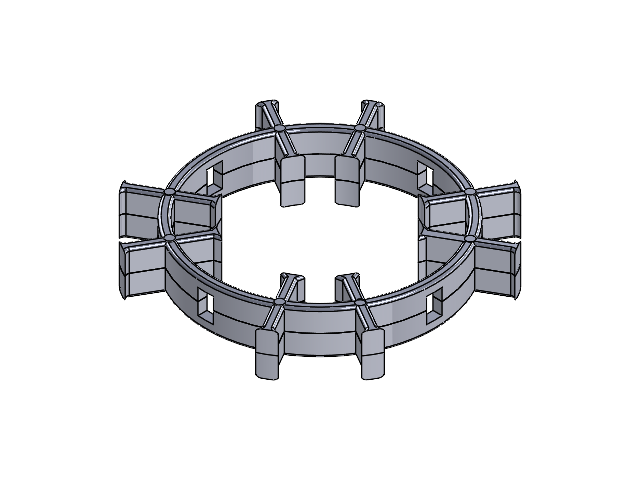
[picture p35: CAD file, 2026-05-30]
25-26/01_Subteams/TMS/TMS 25-26/TMS Prototyping/TMS CAD 2025/Motor + Shroud + Mesh/Meshs/CAD Models/Front Mesh Combined.SLDASM
Front Mesh Piece x 2
Front Pin Piece x 8

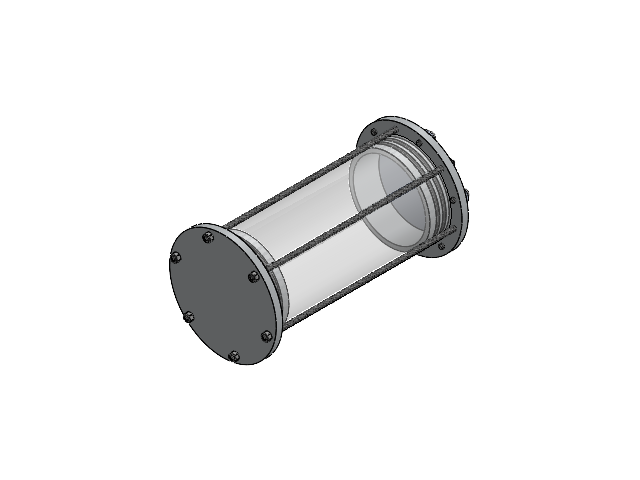
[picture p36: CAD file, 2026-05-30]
25-26/01_Subteams/TMS/TMS 25-26/TMS Prototyping/TMS CAD 2025/Prototype Electronics Enclosure/Prototype Electronics Enclosure.SLDASM
Tube
End Cap x 2
9452K196_Oil-Resistant Buna-N O-Ring x 5
90024A227_18-8 Stainless Steel Threaded Rod x 6
93625A250_18-8 Stainless Steel Nylon-Insert Locknut x 12
Cap Plate
91292A135_18-8 Stainless Steel Socket Head Screw x 6

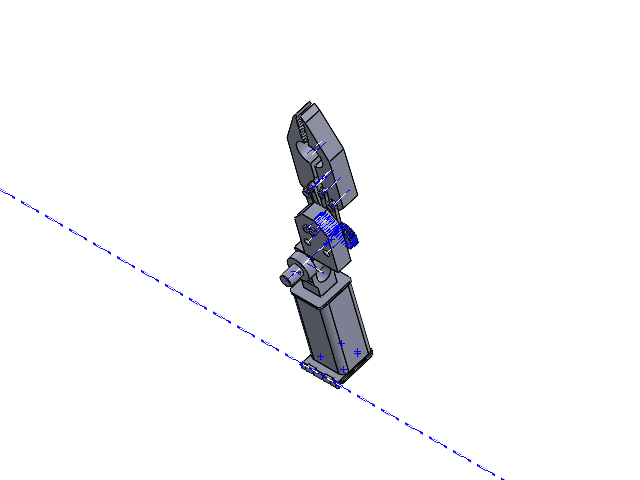
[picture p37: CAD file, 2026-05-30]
25-26/01_Subteams/TMS/TMS 25-26/TMS Prototyping/TMS CAD 2025/Prototype1 Chassis/Arm plus claw assem.SLDASM
HINGE PART 1
Hinge PART 2
Bar
SHORTY LOL
OKAYYY PART 2
OKAYYYY 3
plate for claw
Part4^MR KRABS
Thingy for top part of plate x 2
plug x 4
Bar 2 x 2
Part of Claw x 2
gear x 2
plug 2 x 2

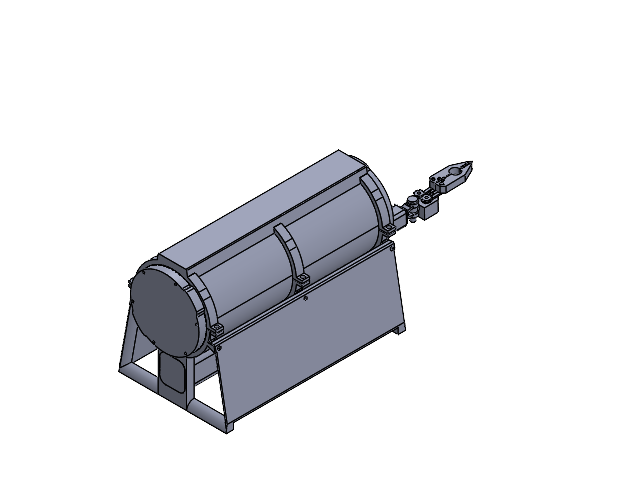
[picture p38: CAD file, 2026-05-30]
25-26/01_Subteams/TMS/TMS 25-26/TMS Prototyping/TMS CAD 2025/Prototype1 Chassis/Final Assembly (Frame, Claw, Enclosure).SLDASM
Prototype 2 (1)
300 mm
Flange 4in diameter x 2
End Cap Blank (Closed, no holes) x 2
Arm 1 on the bot
HINGE PART 1
Hinge PART 2
Bar
SHORTY LOL
OKAYYY PART 2
OKAYYYY 3
plate for claw
Part4^MR KRABS
Thingy for top part of plate x 2
plug x 4
Bar 2 x 2
Part of Claw x 2
gear x 2
plug 2 x 2

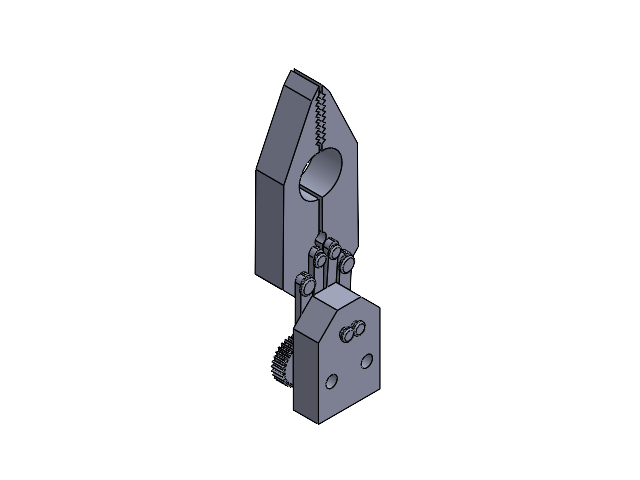
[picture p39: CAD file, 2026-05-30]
25-26/01_Subteams/TMS/TMS 25-26/TMS Prototyping/TMS CAD 2025/Final Assembly (just add claw assembly & arm 1 (Unzipped Files)/MR KRABS.SLDASM
plate for claw
Part4^MR KRABS
Thingy for top part of plate x 2
plug x 4
Bar 2 x 2
Part of Claw x 2
gear x 2
plug 2 x 2

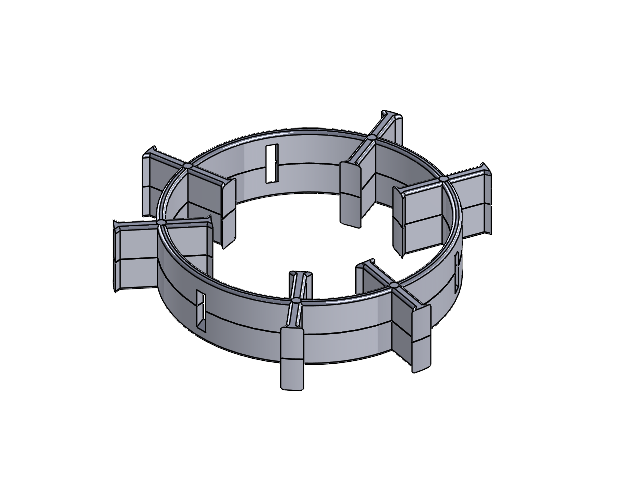
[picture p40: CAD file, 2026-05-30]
25-26/01_Subteams/TMS/TMS 25-26/TMS Prototyping/TMS CAD 2025/Motor + Shroud + Mesh/Meshs/CAD Models/Back Mesh Combined.SLDASM
Back, Bottom Mesh Piece
Back, Top Mesh Piece
Back Pin Piece x 6

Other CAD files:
25-26/01_Subteams/TMS/TMS 25-26/TMS Prototyping/TMS CAD 2025/Final Assembly (just add claw assembly & arm 1 (Unzipped Files)/Arm plus claw assem (23).SLDASM
25-26/01_Subteams/TMS/TMS 25-26/TMS Prototyping/TMS CAD 2025/Prototype1 Chassis/Final Assembly (just add claw assembly & arm 1.SLDASM
25-26/01_Subteams/TMS/TMS 25-26/TMS Prototyping/TMS CAD 2025/Prototype1 Chassis/Scary Chassis Creations/Actual Prototype 6 (Centered, Filleted and Chamfered).SLDASM
25-26/01_Subteams/TMS/TMS 25-26/TMS Prototyping/TMS CAD 2025/Gear (3).SLDASM
25-26/01_Subteams/F&P/Horizontal Mount (2) 110.SLDPRT
25-26/01_Subteams/F&P/Horizontal Mount.SLDPRT
25-26/01_Subteams/F&P/Vertical Mount.SLDPRT
25-26/01_Subteams/GNC/Photogrammetry Test Files/Untitled/model.obj
25-26/01_Subteams/TMS/TMS 25-26/TMS Prototyping/1 x 2 brackets (cut 4) solid.DXF
25-26/01_Subteams/TMS/TMS 25-26/TMS Prototyping/1 x 2 brackets (cut 4).DXF
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

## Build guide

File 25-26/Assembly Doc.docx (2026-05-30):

# ROV Assembly

# Mechanical ROV

3D printing procedures:

– RPS

–FEDC

Bassplate

- Sliced into 4 pieces

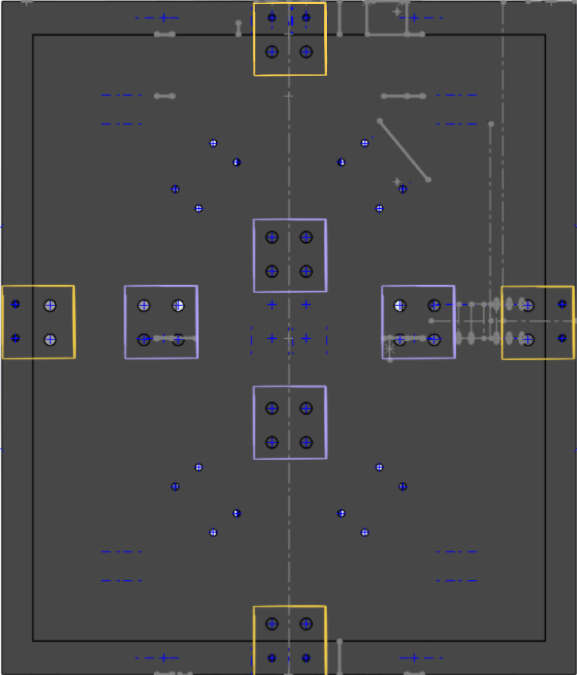
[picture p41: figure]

6.35 mm screws (¼ inch)

6.35 mm nuts

Required:

4 x Aluminum 6061 brackets -> Laser cut

Chassis

- Chassis + Bassplate

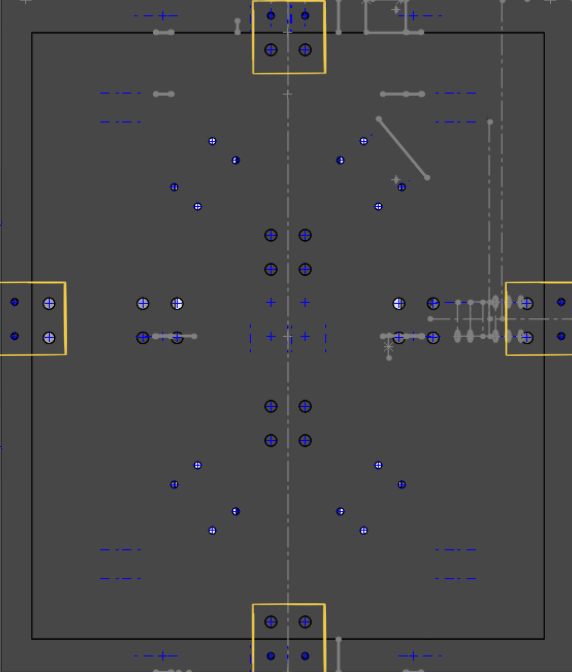
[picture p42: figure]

Required:

4 x Aluminum 6061 brackets -> Laser cut

Top side

M3-18mm screws

M3 heated inserts

Bottom side

6.35 mm screws (¼ inch)

6.35 mm nuts

Electronics Enclosure Platform:

- Slice the Electronics Enclosure Platform and utilize the PLA
  - ROV Electronics Tray for 4" Tube (https://bluerobotics.com/store/watertight-enclosures/locking-series/wte4-etray-r1/)

Polyurethane Potting:

- 2 part potting compound, 2:1 mix ratio
- 5-7 minute working time
- Pour into component
- 24 hour cure at room temperature
- Constant service temperature of -50 to 120 °C (-58 to 248 °F)

Thrusters

- Mesh
  - 3D printed using PETG
  - Attached to thrusters on both sides using a clamping mechanism (or using other methods such as epoxy, superglue, etc.)
- Thrusters
  - Will need to use plates (vertical) or brackets (horizontal) to mount the thrusters
  - 80 Heat set inserts in total are needed to mount the thrusters
    - The heat set inserts will be testing on a singular mount before attaching to the chassis to make sure it provides a secure connection. The length provides 2mm of secure fit at the base, and the inserts are applied through the back and are multidirectional.
  - M4 screws are provided with the thrusters, and extra screws were purchased.

# Float Assembly

# Mechanical

Hull:

- Drill holes in the hull for two sensors on the end cap and two openings for the ballast pump. Total of 4 holes.
  - Ultrasonic sensor hole dimensions:
  - Depth sensor hole dimensions:
  - Ballast hole dimensions:
- Drill small holes (not through) into the top end cap
  - Hole dimensions:
- Epoxy the recovery feature into the end cap holes
- Cut foam into a cylindrical shape, drill holes, then hollow out the inside. (alternatively, cut foam flat to the correct thickness, drill holes, then form it to the inside of the hull).
  - Foam thickness:
  - Hole dimensions same diameters as hull holes
- Epoxy zinc weight to the bottom end-cap
- Epoxy electronics harness to the top end-cap
- Polyurethane-pot the sensors into the end-cap holes
- Apply the heating pad to the underside of the electronics harness

Zinc weight procedures:

- Weigh total system mass (expecting to be slightly too heavy), then drill small holes into the zinc until we are exactly neutrally buoyant.

Electronics harness procedures:

- Lathe diameter to size
- Mill side openings
- Lathe inner diameter to size
- Saw off excess length
- Face the sawed-off side using the lathe facing tool

Ballast:

- Peristaltic Pump will be installed within the float enclosure
- Holes for the intake and exhaust tubes will need to be drilled into the enclosure
  - Waterproofing will be needed to the tubes
- Exhaust tube will be connected to the bag, intake tube will be secured to the bottom of the pump
  - Water bag will be secured to the bottom of the float
    - Will need to either print a bracket to hold, zip tie the bag, or glue to to the hull

# Electrical

# Ground Station Assembly

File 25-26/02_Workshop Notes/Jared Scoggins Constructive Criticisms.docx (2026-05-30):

In no particular order:

#1 Thing:

Like I said in the meeting on Sunday. You are all doing amazing work. Don’t take these critiques personally or negatively. What each of you are doing is just awesome and this project has some very practical implications.

I personally felt it, and during the feedback session I had to say something. I was asked to come help and mentor. To me that is an extreme honor. I felt like I was not honoring the team by only giving criticism. I do realize that criticism was the entire point of the meeting.

Being my first meeting I just want to begin by letting you know that the entire team is amazing. I love this project and the team. I recognize how much work you have all put in and felt bad only giving you all criticism and no praise. To me, that is not very motivating or inspiring.

Adhesives / Sealing / Submersible Housings etc:

The only project I have ever been associated with that failed at OTRC was done by all Aerospace Engineers (All PhD’s not from Texas). They brought their own model and we told them instantly it would leak based on their construction. They belittled us and spouted off specs and their credentials. For example, one of the leaks they had was related to this: 4 inch schedule 40 PVC pipe is rated for over 200 psi. That rating is based on the pipe being horizontal and having its weigh supported by the floor/ground.

They had an electrical umbilical exit a PVC elbow (submerged about 15ft) and contained a 30 foot section of 4 inch pvc that was not secured very well. About 3 minutes into the first test their water intrusion alarms went off. In the waves the moment arm created by 30ft of PVC pipe cracked the joint at the elbow. But it was rated for 200psi…..

That company also did not pay us and is not allowed to do business with TEES or the A&M System. I digress….

Marine Grade or Marine Epoxy – Do not assume the word “Marine” applied to something automatically means it will work. As far as I know there is not a universal industry standard that applies to how well an epoxy will perform at depth. Typically, the “Marine” standards or claims relate to water absorption from being continuously in contact with water for a certain duration, can be applied wet, hold up in extremely humid environments and so on.

What does this mean in practical terms. Research each one and even contact a manufacturer if needed. Don’t assume anything. You most likely will not find any specifications related to head pressure from being submerged. It doesn’t mean something will not work; it just means you are on your own and if it doesn’t work you cannot blame the manufacturer.

For attaching and sealing the final fiberglass hulls to our models we use an epoxy system that takes 24 hours to cure from West Systems (West Marine). If we need something submerged to hold electronics etc, its typically in a submersible container similar to what you have purchased from blue robotics. We use room temperature water, so I typically get aluminum endcaps and mount the electronics that get hot onto one of endcaps, so they also become heatsinks.

Camera housing - The majority of homemade camera housings (and electronics boxes) I have seen tested at OTRC fail. A few of those failures have leaked relatively quickly as the drivers start going down. Most take a little bit and fail withing either the first use or after a few trips from depth to surface. Epoxied joints are the point of failure 90% of the time. 10 to 20 psi is a lot and the case is getting the pressure from 360 degrees. It doesn’t take much expansion and contraction to create a gap big enough for water to start seeping in.

If one reason for using the Pi is its ability to interface with a camera then look for some off the shelf options that are ready to run or possibly a GoPro. I believe there are submersible cameras that will break out to both the mipi connector and USB. Just Google each of them and see what comes up for example – “Submersible mipi camera” or “Submersible USB camera” with the key work being submersible versus waterproof. The next option would be a GoPro. That requires you physically transferring the video over and doing post processing. I am not sure how that would change your workflow.

Other options are out there but these are common and cost less than othersome of the other options.

Enclosure / Electronics / Sensor Temperatures -- I have only had to do this in relation to cooling electronics not every worrying if they were going to be too cold. It is common that if you put electronics in a sealed enclosure they will overheat. The enclosure may just need vents, vents + a fan, or actually cooling from conditioned air. Here is where you make friends with mechanical engineers who have taken thermo.

Look up “electronics enclosure cooling calculator” for the typical steps of how big of an AC to buy so your gear doesn’t overheat. Find one that allows an offset for ambient outside temperatures and also enclosure material. Otherwise ask a mechanical engineering buddy who has taken thermos dynamics to pull out their notes on heat transfer. Just remember to convert watts to btu.

Guidance & Control / Electronics

One of the things that worry me is the Pi controlling everything. That means a bug, glitch, or malfunction in a non-critical system can crash the entire operation.

A generic rule of thumb is typically things that are critical should not be controlled by something that boots up. Raspberry Pi outputs can act very strange and unpredictable when it crashes and/or during the reboot process. Here is what I have witnessed.

- Typically and output will go either hi or lo and it may not be repeatable. It also doesn’t matter if its straight digital – PWM – connected to an IC via some kind of serial bus such as I2C – SPI.
- Rebooting from a crash or problem typically takes longer than a commanded reboot (and no updating is occurring)
- The pi 5 has a lot more horsepower but I have personally experienced a few issues after a crash (most crashes are my fault because I am developing – and so is the ROV team.) Crashes should be expected when beta testing.

Some of the ancillary problems after a crash is that it takes another reboot or running a command to restart a service because of the newer OS requiring a virtual environment. The packages have to be in a venv. Once the bugs are worked out its fine but you will be developing until you pack up and go home from Canada.

Some ideas on this. The Pi 5 is awesome and very easy to use. It plays nicely with others from networking, USB, I2C, SPI and common protocols. I love raspberry Pi’s and personally own and use a lot of them. One of my favorite accessories is the cases from Argon40. Specifically, the NVMe SSD cases. A Pi5 with an NVMe SSD connected via ribbon cable to the pcie bus makes a very fast and efficient Pi.

How about a hybrid solution. Something like the guidance & control system is controlled by something that’s more of an embedded system and it uses one of its communication protocols to talk to the Pi.

Not sure of everyone’s comfort level with coding and hardware. The dsPIC33 series microcontroller is really awesome and has awesome libraries that are perfect for thruster control. They have different development boards available. It’s essentially a hybrid digital signal controller. They even have two-core processors available. For example one core could process all the IMU and navigational data plus Kalman filtering while the other core take the input from controls – very smoothly operates the thrusters and talks to the PI over I2C (or networking protocols – or whatever…. This is an example).

In this case, you could at least control the ROV regardless of the status of the Pi. I2C or some other communication protocol would feed the Pi all the information from the control system so you can then have the Pi do all the tasks and talk to all the sensors. But basic critical control would be the sole responsibility of the embedded controller.

One way to look at it is this: If you lost a family member in a plane crash, where the aircraft malfunctioned on landing. Afterwards the investigation revealed that the navigation system and instrument landing system was controlled by the same computer module that played all of the movies and infotainment on each of the seatback. And they did it because it was cheaper to do that so you could watch your position in real time over a moving map while in flight.

Would the manufacturer be negligent?

I know that story is an exaggeration and against the rules. But I think it plays out here as this: You have been warned. Who do you point the finger at if this happens in competition. *** I understand the clock is ticking and you may have to proceed with what you have *** That’s also life. So do what you need to do – no one’s life is at stake here. But take the warning seriously.

The dsPIC33 IC mentioned above is just an example. They do sell development boards but for timeline purposes something like Arduino may be more practical.

Maybe for next year when you have more time and a year of learning under your belt an FPGA can be used to do all the processing and the Pi is just a way to interface to your various systems and make it easy to get data from. If you want to work in the Aerospace industry and have FPGA experience as an undergrad then your employability and starting salary will be greater than your peers.

Any plans to add leak detection sensors? You can even diy those.

5 Degrees of Freedom

This is one of those cases where I just don’t quite see your vision. Which means my concern of not having 6DoF thruster control might just be in my head and not really a concern.

I just have a feeling that it will be needed. It is so easy to get off-axis and literally get in a bind. Attaching a buoy is such a great task. With your thrusters also disturbing the water and influencing the buoy. I could easily see the ROV having a tough time because roll cannot be dampened. I can even see a scenario where there is roll induced motion and the ROV relatively stationary trying to do a task and the thrusters, buoy, waves, currents etc all start exciting the ROV to roll because its not constrained. If that’s the case your center buoyancy might also be the pivot point for uncontrolled roll oscillations. Those can grow and amplify to the point where it gets realy out of hand if the external force causes the ROV to oscillate at (or close to) its natural period.

There is also the ability to position the ROV more efficiently to do tasks.

Misc

You may need to do some tests to verify and/or set youth center of gravity etc. That will make things much easier to set your center of buoyancy.

Once you have you CoG you can get the yaw period using two cables (bifilar suspension) and also calculate the Moment of Inertia. That will inform you of the torque required from your thrusters for a specific rate of turn.

Additionally, you probably should do a ‘dip test’. Where you weigh down the ROV so it can sink. Then attach everything to a load cell and zero out the load cell. Then measure the weight at varying elevations and see if that matches your profile and aligns with your center of buoyancy.

Also, under Misc – If you even think it may be a possibility you will be traveling for the competition make sure you have a passport and know where it is. If you have not traveled for a while and it is at your parents’ house, make sure to get eyes on it. As your parents to actually pull it out and look at the expiration date, etc.

I say this because students don’t check their expiration dates or wait to the last minute to get a passport and it can cause a lot of issues. You will not be able to board a plane without it.

Last Thing

Working with students over the years, I am adding this below.

Working in groups, there will be conflict, its normal. I am sure some conflict has already happened.

Working in groups where you have incredibly talented and capable people means you will have a bit more conflict.

This is the only thing I will ask of you: “Fight like family, like you care about each other.”

In a weird way, it is like professional boxing or MMA. It means that when conflict does occur there are still certain boundaries. You do not hit below the belt (metaphorically). I imagine after spending a lot of time with each other you all know personal details about each other.

Similar to family, you know your family members’ triggers and pain points. You could easily bring things up that really hurt the other person. But the only outcome of that is pain for someone. That is out of bounds.

If you find yourself in an argument do not try and kill the spirt of the other person. Ask yourself if this argument is worth fighting for and to what degree. It gets tricky here because you don’t want to destroy someone’s spirit nor you want to be seen as someone who can be walked on and talked to disrespectfully. Know your audience and the style of communication that will be most effective to create understanding versus more conflict.

But if you are really angry walk away. It is fine to be honest and say I am extremely mad right now and I don’t want to overreact, I am walking away for now and we will talk about it later.

Sorry to end this. Just want to make sure we are all on the same page. I am excited to see what y’all make.

Jared

Jared Scoggins | Assistant Director
Offshore Technology Research Center | Texas A&M Engineering Experiment Station
3400 TAMU | College Station, TX 77843-0000

ph: 979.845.6000 | mobile: 979.218.1415 | jscoggins@otrc.tamu.edu
– – – – – – – – – – – – – – – – – – – – – – – –

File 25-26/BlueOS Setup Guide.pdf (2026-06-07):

# Steps for Running BlueOS on Raspberry

Pi

### 1. Download the BlueOS Image and Flash the MicroSD Card

Start by obtaining the correct operating system image for your Raspberry Pi hardware. The ARMv7 architecture image covers models up to the Raspberry Pi 4, while the ARMv8/ARM64 image is utilized for the Raspberry Pi 5.
- Prep the SD Card: A fresh MicroSD card with at least 32GB of capacity is highly recommended. While smaller cards can boot the OS, the extra storage is essential for onboard data recording and buffering high-bandwidth video streams.
- Flashing: Open BalenaEtcher, select the downloaded OS image file, choose your target MicroSD card, and flash it.
Relevant Resources:
- Download the latest OS image from the BlueOS GitHub Releases page. (https://github.com/bluerobotics/BlueOS/releases)
- Download the flashing software from the BalenaEtcher website. (https://etcher.balena.io/)

### 2. Boot the OS and Establish a Direct Connection

Insert the flashed SD card into your Raspberry Pi and apply power. The initial boot usually takes about two minutes because the operating system needs to expand its filesystem to utilize the full capacity of your SD card.
- Wired Connection: Connecting the Pi directly to your computer's Ethernet port provides the most stable connection for initial configuration.
- Wireless Hotspot Fallback: If BlueOS does not detect a familiar Wi-Fi network within 5 minutes of booting, it will automatically start broadcasting its own wireless hotspot. If you see the "BlueOS" network pop up in your Wi-Fi settings, the correct password to connect is blueosap.

### 3. Access the Web Server Interface

BlueOS operates entirely as a headless system. You will not use an HDMI monitor; instead, you manage the system through a web dashboard.
- Navigating to the Dashboard: Open your web browser and type in http://blueos.local or http://blueos-avahi.local. If you are wired in via Ethernet and the .local address isn't resolving, you can access the interface directly using the default IP address: 192.168.2.2.
- Internet Access: Once you are in the interface, click the Wi-Fi indicator in the header to connect the Pi to your local internet network. This allows the system to pull down the latest software updates and extension registries.
Relevant Resource:
- Read through the network troubleshooting steps in the BlueOS Official Documentation. (https://blueos.cloud/docs/)

### 4. Explore Features, Telemetry, and Extensions

The dashboard acts as the central command hub for hardware interfacing and system logic.
- Video Streams: Plug your USB camera into the Pi. BlueOS automatically detects H.264-capable cameras and begins streaming the feed. You can configure multiple camera inputs and adjust stream settings in the Video Streams menu, which is the foundational step before feeding that visual data into photogrammetry software.
- Control Systems and Telemetry: Navigate to the Autopilot Parameters and MAVLink Endpoints pages. This section allows you to interface with connected flight controllers, route telemetry data, and fine-tune variables like your PID control loops.
- Extensions: BlueOS supports a robust ecosystem of Docker-based extensions. You can browse the BlueOS Bazaar within the interface to install community-built tools, or write your own custom extensions to handle specialized photogrammetry processing directly onboard.
Relevant Resource:
- Learn how to write and deploy your own software tools in the BlueOS Extensions Documentation. (https://blueos.cloud/docs/development/extensions/)

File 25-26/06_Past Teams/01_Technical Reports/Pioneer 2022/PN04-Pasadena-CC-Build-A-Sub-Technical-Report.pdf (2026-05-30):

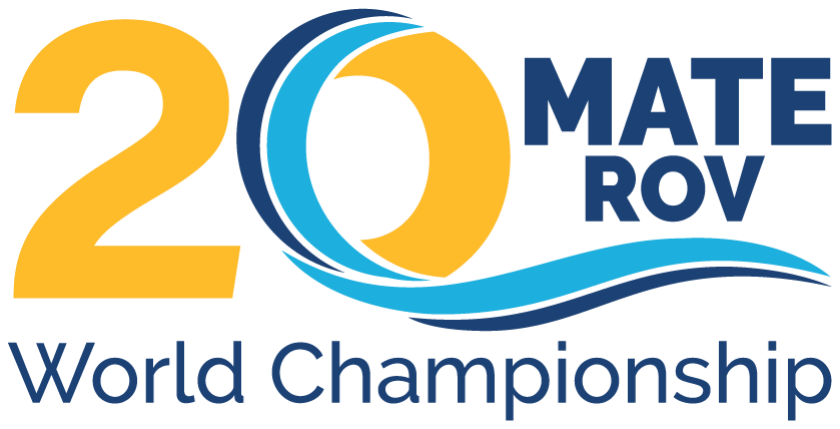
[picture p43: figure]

## Pasadena City College Pioneer Class PCC Care Bears

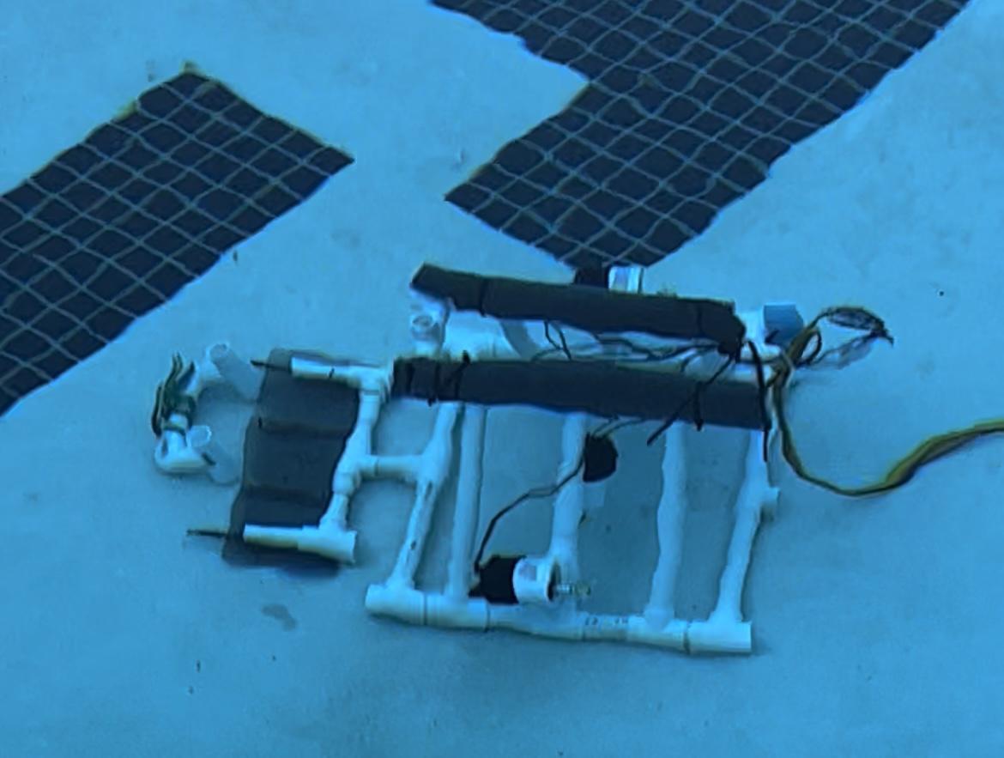
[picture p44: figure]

PCC Care Bears 1

Abstract

This report documents the finalized design for the underwater remotely operated vehicle (ROV). The purpose of the ROV is to service Marine life and help preserve Ocean health. PipeDream is Pasadena City College’s first ROV. This document was created in the Spring of 2022 for the 20th MATE ROV World Championship Competition. This report outlines the mechanical configuration and design, software and hardware architectures, power, planning and a number of design process issues.

Acknowledgements

The Technical Documentation was written by the following people:
- Frank Alas - CEO, Lead Engineer, Testing & Operations
- Mariana Aldama - CFO, Lead Engineer, Systems Engineering & Design Integration

Table of Contents

Design Process
Building Pasadena’s first remotely operated vehicle (ROV) began 9 months ago, with new members for the school’s first time. The frame design, originally labeled as the vectored TriggerFish ROV Frame, was an inspiration used from the MATE ROV Powerpoint slides provided by marinetech.org.

Design Specifications and Constraints
This section will cover the details regarding the system and task specifications for the ROV. As well as limitations and constraints based on the MATE ROV competition rubric.

System specifications include:
- Must be able to fit in a 1 meter by 1 meter hole in the “ice.”
- Must weigh less than 35 kg (or 77 pounds).
- Vehicle must overcome 3 obstacles such as placing a fish into a bucket, replacing seagrass, and unhook the ghost nest.
- Materials compatibility requirements must be met to be used underwater.
- Do not exert a lot of force onto the ROV as there are limitations on the material.

### 2.1 Facility Constraints

Facility limitations include pool access to test drive the ROV. Were limited to one day per week. Testing was difficult to do as a result.

### 2.2 Environmental and Safety Issues

The following is a list of safety issues and requirements for personnel or equipment operating near the ROV, Pipedream, meant to highlight relevant items needed to handle with extra care.
- Power Supply set to one phase to not burn out the fuses on the analog control board.
- ROV must be turned on underwater to prevent the motors from burning out.
- A check-list guide we follow before placing the ROV into the water.

### 3. Design Overview

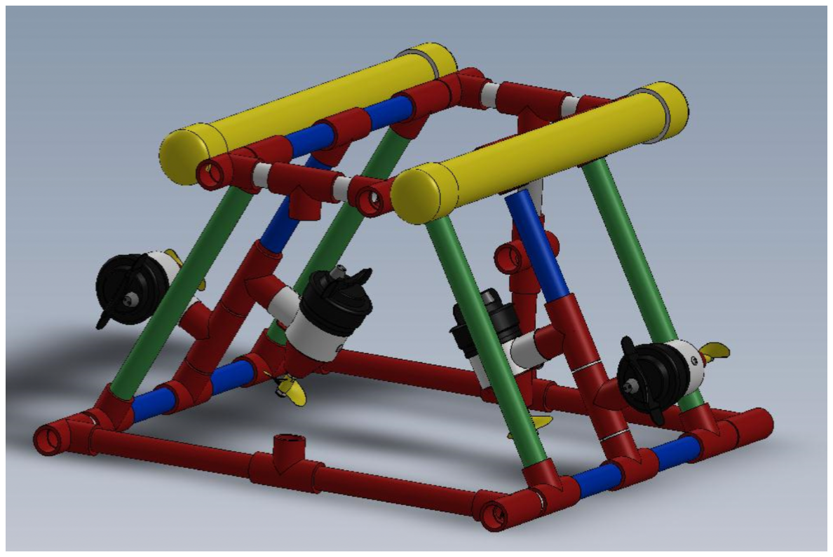
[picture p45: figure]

Figure 1: MATE ROV Powerpoint, Chapter 1, Slide 20. www.marinetech.org. TriggerFish ROV Frame (isometric view)

The design for PipeDream revolves around a trapezoid shape. The framework of the ROV has a 45-degree vector design. To ensure that the force of the motors can lift the weight of the ROV in the water, the motors were strategically placed. There are four motors: two motors to Surge (forward/reverse) and Yaw (turn), and two motors to Heave (up/down) and Sway (crab), which are vectoredly positioned. We learned that the net forces of the vector-positioned motors cancel out when the motors run in opposite directions causing the horizontal vector components to add together and shift the ROV towards any x-axis direction using the motor to Surge. The frame was made out of ¾ - inch polyvinyl chloride (PVC) pipes to meet the weight requirement yielding the maximum points, along with having easy mobility in the water. Instead of using buoyancy foam, poodle noodles were incorporated with zip-ties as a result of back shipping.

An arm scooper was incorporated to the bottom right side view as a substitution for an electrical robotic arm to ensure tasks were achieved. The prototype was made out of thin steel wire and held by hot glue, which was then replaced with a 3D solidworks model composed out of acrylonitrile butadiene styrene filament for UV resistances, light material, and tough loads.

The control system that was used was the Barracuda controller, which is composed of two printed circuit boards and has two joysticks. Each joystick has a 10k ohm potentiometer that gives a variable voltage to the integrated circuit on the Sabertooth motor controller. This signals the H-bridge, which controls motor speed and direction to the motors on Pipedream. The designers of the Barracuda board incorporated 4 LEDs assigned to each motor to indicate to the user the direction of each motor: the LED’s color range of either red (reverse) to green (forward). The left joystick moves two motors, forwards, backwards, and turns the ROV side-to-side. The right joystick moves two motors in the vertical direction, up and down, which includes strafing or crabbing motion.

The Barracuda controller kit came with a camera filter board to enable camera and monitor inputs.The Barracuda controller has additional features that were not used.
The tether used to connect the ROV to the control board has two wires for each motor, totaling to 8 wires.

### 3.1 Safety measurements

The tether has a strain-relief to prevent any damage from occurring. Wires, thrusters, and cameras were waterproofed. Fuses were found throughout the controller board and on the power supply cord. Safety guards were designed for the propellers on Solidworks to meet the MATE ROV Competition safety and regulations standards. The assembled view is composed of three part files as shown in the exploded view on Figure 1.3. A snap and fit design was integrated to tightly lock all three parts together while being on the thrusters, propellers, and PVC pipes.

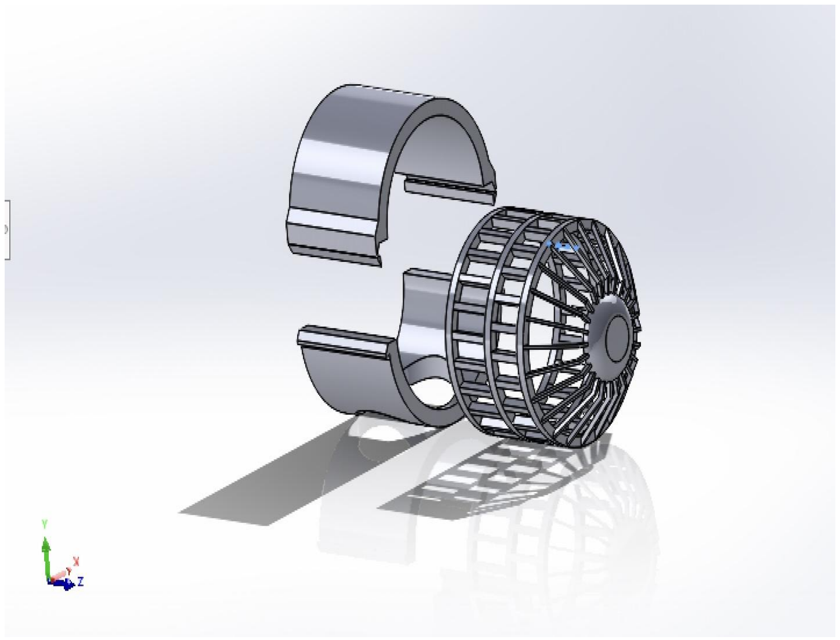
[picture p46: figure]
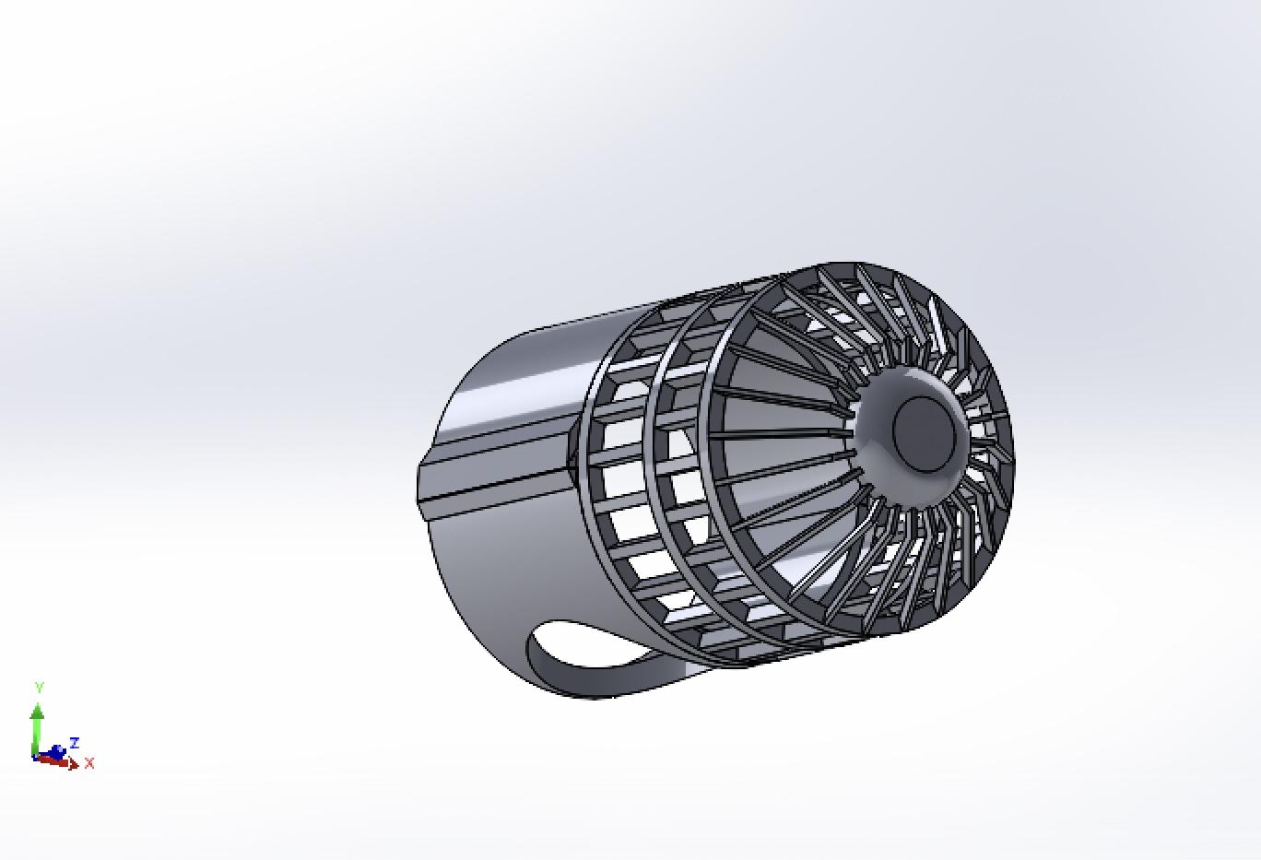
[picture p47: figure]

Figure 1.2: Propellor safety guard solidworks design (isometric view) | Figure 1.3: Propellor safety guard solidworks design
(exploded view)

Cost
1x Barracuda ROV with Thrusters and Tether for $1,200.00 each
2x Wire Soldering Lab Kit - One for $5.00 each
2x Pufferfish Practice Board - 1 for $6.50 each
1x Powerwerx 12V DC Power Supply w Powerpole outlet + GFCI for $160.00 each
1x Powerwerx TRIcrimp Powerpole Connector for $39.00 each
1x Underwater Robotics: Science, Design, and Fabrication (Revised Edition) - One Copy for $120.00 each
1x pool foam for $2.00
2x PVC pipe ¾ - inch by 10 feet for $7.00 each
2x 20-pack ¾ - inch Tees for $11.00 each
1x Zip Tie Pack for $2.00 each
1x Triggerfish / Barracuda Video System Kit for $210.00

Total Cost (after taxes): $1,778.50

Critical analysis of testing and troubleshooting

We encountered a few issues throughout the building process of our control box and our framework. Initially, the team intended on using a gaming controller to move the rover underwater. The initial thought process was that a controller would allow us to move the ROV easier due to the nature of the positioning of the analog sticks; for example, what we can control with two hands on the control box would only require two thumbs on a controller. Due to the complexity of the coding required, as well as the time constraints, we returned our focus to using the analog sticks. Here we encountered another set back. Our y-axis joystick was not getting the sufficient voltage which we would need in order to move from the bottom of the pool to the surface. A solution came from using a spare joystick and resoldering it.

A very crucial set back was that, due to covid restrictions, access to the pool at Pasadena City College was limited. Testing in the water did not become available until around April of 2022. Troubleshooting movement in the water would have to wait until we were given clearance.

References

MATE Underwater Robotics. “ROVs 101 - An introduction to ROV structure & the basics behind designing and building your very own underwater vehicle.” www.marinetech.org.

MATE Underwater Robotics. “Constructing the Barracuda Control Box in Analog Mode” www.educate.materovcompetition.org

SeaMATE BARRACUDA. “Instructions for the SeaMATE Barracuda ROV Kit” www.marinetech.org.

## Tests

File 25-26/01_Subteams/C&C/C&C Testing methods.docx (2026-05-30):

ROV Testing Methods:

Camera Testing

Product:

- For the 4k camera, we need to test if it is capable of transmitting the large amount of data feed from it given the high quality output of it.
  - Plan: Test the 4k camera by calculating the bits per second of the 4k camera and check microcontroller and tether transfer rate
  - C&C 5.2.1b, C&C 5.2.1c, C&C 5.2.3
- Ensure that the brio100 can connect to the monitor through the raspberry pi
  - Plan: Test the brio100 by connecting to the the Pi and connecting the Pi to the monitor
  - C&C 5.2.2, C&C 5.2.4
- Ensure that the cameras are capable of seeing in the underwater conditions
  - Plan: Put the cameras within their underwater housing and put them in a bath, cover the bath with a sheet and see how well the camera+light are able to output video to the monitor/picture to the Pi, do this with the photogrammetry camera and navigational camera
  - C&C 5.2.3, C&C 5.2.1a, C&C 5.2.1b, C&C 5.4.1

Microcontroller Testing

Product:

- Ensure that the microcontroller is able to handle all the data that will run through it.

Temperature Sensor Testing

Product:

- The temperature capabilities of it will need to be tested along with the accuracy.
  - Plan: Dunk it into a cool tub of dry ice. We can test the temperature it outputs against a traditional thermometer.

Light Testing

Product:

- The lights will need to be tested alongside the camera to ensure it can provide clarity underwater for the cameras.
  - Plan: Test different setups of the light in relation to the camera to see which provides the best clarity for the camera in dark environments underwater.
- Temperature rating testing
  - Plan: Dunk it into a cool tub of dry ice.
- Light changing testing
  - Plan: Ask EPS before testing about possibly sending lower current to the lights to dim when needed.

Depth Sensor Testing

Product:

- Temperature rating testing
  - Plan: Connect the depth sensor to the raspberry pi 5 and connect the microcontroller to a computer to view output of the depth sensor. To reach as close to -25 degrees Celsius, dunk it into a cool tub of dry ice. Dunk the Depth Sensor itself into the water and see if it can output the temperature.
- Accuracy testing
  - Plan: Use a thermometer (such as a laser thermometer meant for cold temperatures) to compare and contrast what the depth sensor says vs the thermometer.

C3 Station Testing

Product:

- The laptop monitor will likely output in 1080p and the camera records in 1080p. Ensure the camera feed can properly be displayed to the laptop
  - Plan: Check the pilot view on the laptop and ensure that the vision is clear and not having issues with the feed.
- Ensure the Logitech controller can properly pilot the ROV from the C3 station
  - Plan: Connect the controller to the raspberry pi in the C3 station and ensure all our button commands are working properly

Float Testing Methods:

Product:

- Check the accuracy of depth reading on depth sensor
  - Plan: Use a tub of water to have the depth sensor read data in and constantly measure the true depth of the sensor as we move it up and down through the tub
- Check reliability of data transfer over bluetooth
  - Plan: Have a test run with the bluetooth to raspberry pi and ensure the data reads correctly, matching the provided format we need to have our depth data in

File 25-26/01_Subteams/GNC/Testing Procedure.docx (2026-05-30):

Testing Motion

be sure to name specific requirements

360 Test

- 360 Test with cameras attached to the ROV
- check for shifting of camera while rotation
- check that connections are not coming loose for camera while rotation

Precision Test

- Check cameras to see if the images come blurred or not
- Test how precise movements are to specific locations

Speed/Control

- test various speeds such that it can maintain clear images, intact parts, etc.

Camera

- test for image quality
- test for stability on camera in movement

Procedure

short procedure and relationship between test getting designed and testing, purpose of test

The main criteria to be tested revolve overall motion and control of the ROV, as well as producibility of accurate images. The ROV is to rotate at different degrees of freedom, checking at each phase whether the ROV remains stable in its position. If such tests fail the ROV is to be examined for areas of disbalance and to be corrected accordingly. In terms of getting accurate images, the ROV’s camera configuration is to be tested for blurred or unclear images during movement. Lighting and orientation should be corrected such that the camera is getting clear images. With regards to control, the ROV should be tested at varying speeds, with each increase still maintaining stability.

Camera

- tested different exposures and shutter speeds to see camera quality to reflect underwater surroundings

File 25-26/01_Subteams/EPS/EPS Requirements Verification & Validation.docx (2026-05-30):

EPS Requirements Verification & Validation Plan

EPS ROV Requirements | Verification & Validation Plan
1.1.1 | Verification will be achieved through physical inspection and continuity testing of the main power entry point. The team will confirm that the robot receives power through a single designated connection and that no alternate power entry paths exist. The installed fuse will be inspected for correct rating and placement in accordance with competition guidelines, and continuity testing will verify that all incoming power passes through the fuse before distribution.
1.1.2, 1.1.3, 1.1.4 | Verification will be achieved by measuring the input voltage at the tether connection using a calibrated multimeter to confirm a 48 V supply. The team will trace the power path from the surface power supply to the ROV to ensure that the voltage is delivered directly and requires no surface-side adjustment during operation. Functional testing will confirm stable power delivery at the required voltage.
1.1.5 | Verification will be achieved by measuring voltage levels at all power distribution points and converter outputs using a multimeter under both idle and load conditions. These measurements will confirm that no subsystem or converter increases the voltage above 48 V anywhere in the system.
1.1.6, 1.2.4, 1.3.2, 1.3.3 | Verification will be achieved using an oscilloscope to monitor all power rails for voltage spikes, ripple, or transient behavior during startup and full-load operation. Current draw will be measured using inline current sensors and a clamp meter to confirm it remains within specified limits. Individual subsystems and sensors will be tested to ensure they operate within rated current values and do not introduce overcurrent or short-circuit conditions.
1.2.1, 1.2.2 | Verification will be achieved through a complete system inspection and power audit to confirm that no onboard batteries are present. Each sensor and electronic subsystem will be traced to its power source and verified to operate using approved low-voltage or USB-based supply lines.
1.2.3 | Verification will be achieved by reviewing wiring schematics and performing continuity and isolation testing between subsystems. Tests will confirm that sensors cannot supply power to propulsion or video systems and that no reverse power flow exists between subsystems.
1.3.1 | Verification will be achieved by conducting a controlled shutdown test in which main power is disconnected while the system is operating. The team will observe and record shutdown time and inspect all components afterward to ensure no damage or abnormal behavior occurs.
1.4.1, 1.4.3 | Verification will be achieved through inspection of all seals, gaskets, and cable penetrations on the electronics enclosure. A controlled partial submersion test will be performed while monitoring for leaks. After testing, the enclosure will be opened and inspected for moisture. Cable strain reliefs and tether connections will be inspected to confirm proper mechanical support.
1.5.1, 1.5.2 | Verification will be achieved by operating the ROV using the surface control computer and confirming that all commands originate from and are processed through this system. Signal integrity and latency will be evaluated during operation to ensure accurate and timely response. Voltage levels of control signals will be measured to confirm they remain within approved low-voltage limits.
1.6.1 | Verification will be achieved through a full system component inspection to confirm that only approved DC adapters and components are installed. Component datasheets will be reviewed to verify compliance.
1.6.2, 1.6.3, 1.6.5 | Verification will be achieved through detailed inspection of wiring and connectors. The team will confirm that wiring is properly routed, securely fastened, and compliant with standard color-coding conventions. Mechanical checks will ensure all connectors are secure and appropriately rated. Continuity testing will confirm correct electrical connections throughout the system.

EPS Float Requirements | Verification & Validation Plan
1, 4 | Verification will be achieved through electrical testing and analysis under idle and full-load conditions. Using a calibrated multimeter and inline ammeter, the team will measure EPS output voltage and current at representative load points to confirm the system supplies no more than 12 VDC and does not exceed 5 A. Full-load current will be recorded and compared with the installed fuse rating to verify that the fuse is properly sized and rounded up to the nearest available standard rating.
2, 6 | Verification will be achieved through physical inspection and measurement. The team will confirm that a single fuse is installed in the positive power path within 5 cm of the positive battery terminal using a ruler or caliper. Inspection will also verify that the fuse and battery pack are visible or readily accessible for amperage verification without requiring full system disassembly.
3 | Verification will be achieved through inspection and documentation review. Battery labels and manufacturer datasheets will be checked to confirm that only NiMH or AGM batteries are used. A full system inspection will ensure that no LiPo or alkaline batteries are present within the EPS.
5 | Verification will be achieved through environmental testing. The EPS assembly will be placed in a temperature-controlled chamber or cold environment set to −10 °C and operated continuously for at least 10 minutes. During this period, voltage stability, current delivery, and overall functionality will be monitored to ensure reliable operation.
7 | Verification will be achieved through dimensional measurement of the fully assembled EPS within the float structure. Measuring tape and calipers will be used to confirm that the total assembly length is less than 1 m and the diameter does not exceed 18 cm.
8, 9 | Verification will be achieved through documentation and schematic review. The team will confirm that EPS documentation includes measured idle and active full-load current values and a clear justification for fuse selection. The System Interface Diagram (SID) will be reviewed to ensure it contains a standard fuse symbol, accurate wiring representation, and annotated measured current values consistent with test results.

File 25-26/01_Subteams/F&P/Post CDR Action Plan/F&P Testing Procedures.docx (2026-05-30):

Flight Controls

Simulations:

- Thrust allocation works effectively in a simulated environment, assuming neutral buoyancy, without considering current.
- Thrust allocation works effectively in a simulated environment, assuming neutral buoyancy, and considering current, which creates interfering horizontal forces that need to be counteracted. - this is something that we will confirm with ARdupilot
- ~~Thrust allocation can be tweaked in terms of a measured efficiency, in the case that a thruster is outputting a force lower than the ideal output. (this is a fail safe method)~~
- ~~Software is compatible with hardware from GNC~~

Physical Testing:

Thrusters:

- ~~Thrusters can be mathematically proven to provide desired thrust~~
- ~~Thrusters are 3D modeled and attached to the body of the ROV created by TMS~~
- ~~The electronic connections from the thrusters are proven to be waterproof by physical testing (this is an EPS collaboration thing) i this is provided from the manufacturs~~
- ~~Vertical thrusters work in two directions, if the ROV employs a neutral buoyancy mechanism~~
- ~~Thrusters operate in provided temperature range~~
- ~~Mesh minimizes thrust force loss through design~~
  - ~~Conduct testing through both ansys/solidworks and by setting up an in water test.~~

Buoyancy (Solidworks) - Float (on the backburner)

- ~~Basic computational fluid dynamics for the hydrodynamics of the ROV~~
- ~~Sheer stress calculations induced by the fluid – irrelevant for the speed of our ROV~~

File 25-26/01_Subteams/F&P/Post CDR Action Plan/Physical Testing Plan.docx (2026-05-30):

# Physical Testing (once the ROV is constructed)

ROV

- Determine method of positioning center of mass on the bassplate, and the optimal weight and location based on the thrust vectors
- Calculations for center of gravity
  - Set the center of buoyancy based on the center of gravity
- Get the yaw period using the bifillar suspension w/ 2 cables to calculate the moment of inertia
  - Info will go to GNC
- Do a dip test to get the “water weight” of the ROV
  - Find any leaks and unforeseen issues
  - Measure at different depth for buoyancy calculations
    - Finding amount of buoyancy needed at different depths and pressures (shouldn't vary all that much)

Float

- Determine the center of buoyancy and center of mass location for the float, and the optimal stability percentage for providing a restoring force without intense oscillations
  - This can be varied using the location of the pump bag, and by changing the position of the center of mass

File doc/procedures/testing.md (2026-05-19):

# Testing Procedures
This document outlines the testing protocols for the Team Oceanus ROV systems.

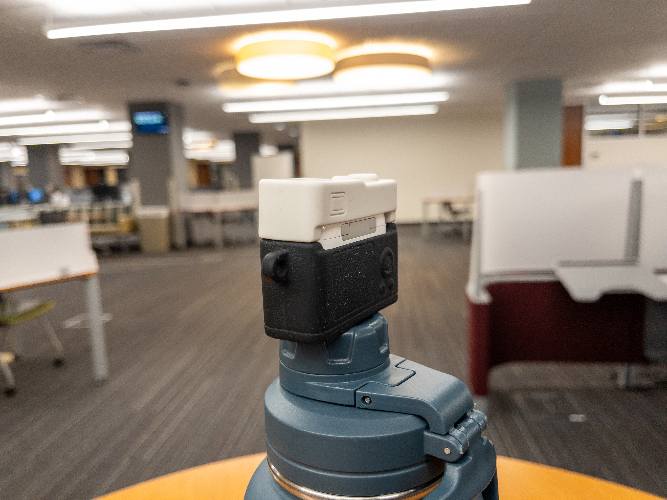
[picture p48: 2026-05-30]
25-26/01_Subteams/GNC/Photogrammetry Test Files/APC_0033.jpg

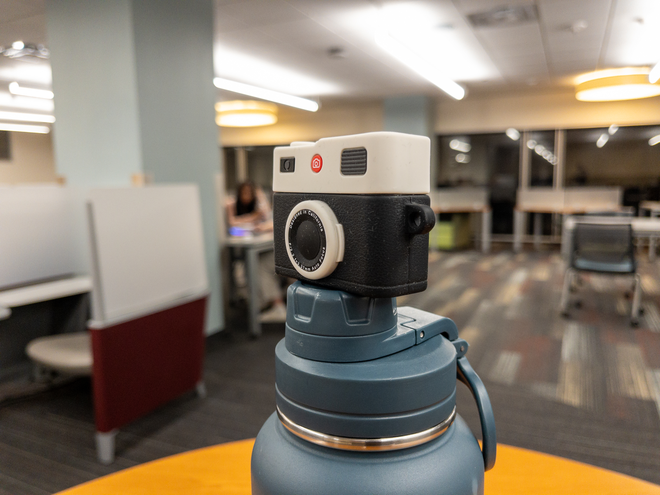
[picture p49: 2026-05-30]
25-26/01_Subteams/GNC/Photogrammetry Test Files/APC_0027.jpg

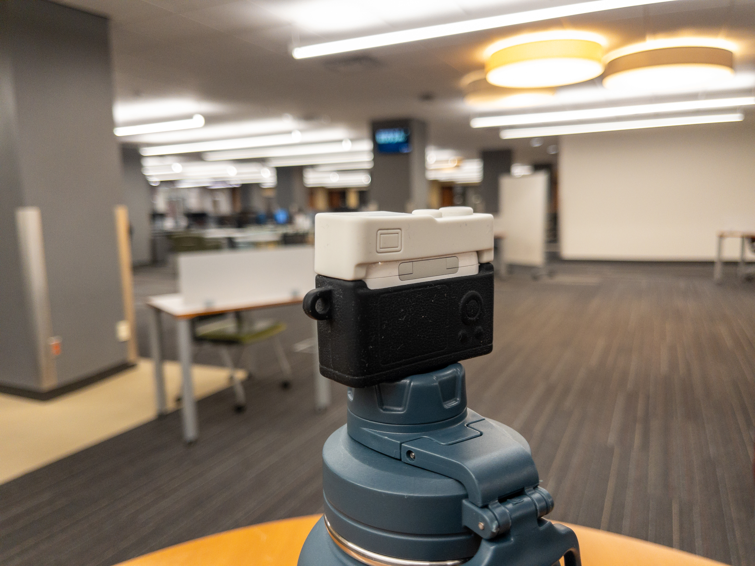
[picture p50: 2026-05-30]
25-26/01_Subteams/GNC/Photogrammetry Test Files/APC_0034.jpg

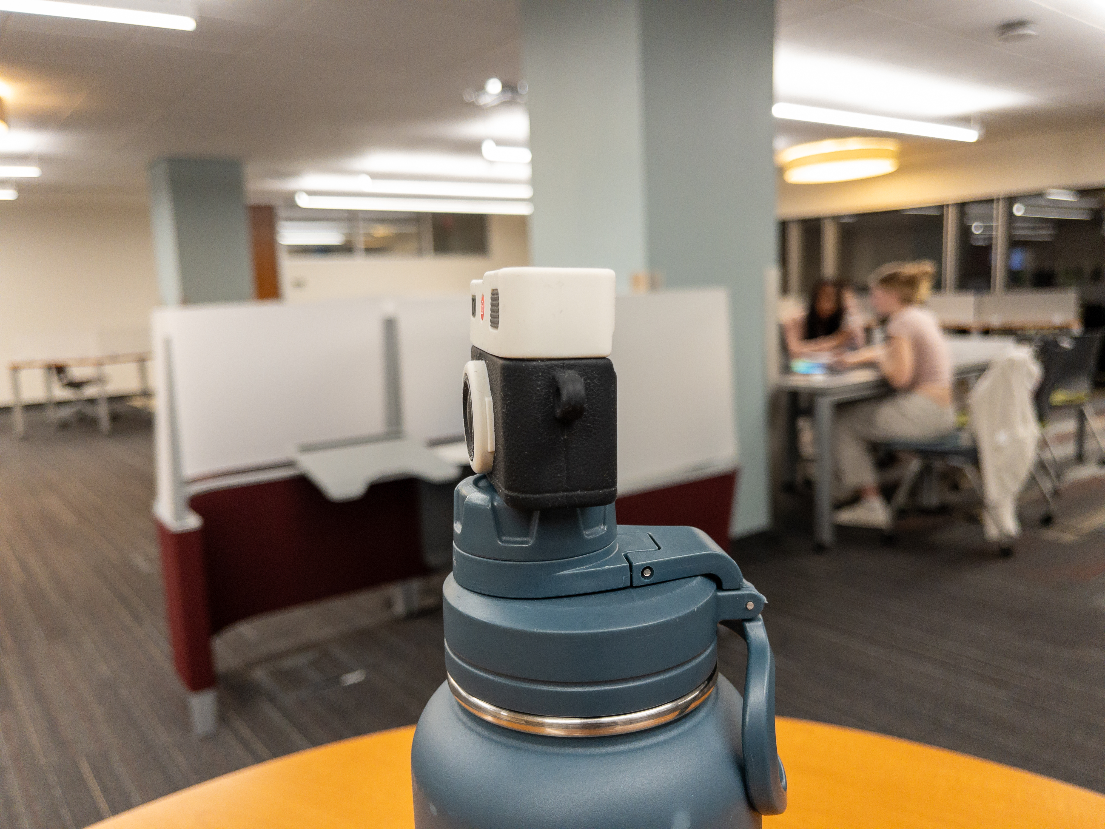
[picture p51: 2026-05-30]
25-26/01_Subteams/GNC/Photogrammetry Test Files/APC_0030.jpg

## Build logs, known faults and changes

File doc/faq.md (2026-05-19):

# FAQ
Frequently Asked Questions for Team Oceanus.

## General
- **What is MATE ROV?**
  [MATE ROV](https://materovcompetition.org/) is an underwater robotics competition that challenges students to solve real-world problems while gaining career-level experience. Team Oceanus will be competing within the [Pioneer](https://materovcompetition.org/pioneer), one of the most advanced levels of this competition, which means that we must work hard, apply the systems of engineering properly and try our best if we want to show MATE ROV how great Oceanus is!

## Main Delivery Documents

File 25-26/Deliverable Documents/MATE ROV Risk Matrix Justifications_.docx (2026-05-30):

| 1 | 2 | 3 | 4 | 5 | | | | 1 | 2 | 3 | 4 | 5
L i k e l i n e s s | | | | | 1 | 5 | | L i k e l i n e s s | | | | | | 5
| | | 5, 7 | 8,3 | 6,2 | 4 | | | | | | | | 4
| | | | | | 3 | | | | 5,9 | 1,3 | | | 3
| | | | 9 | 4 | 2 | | | | 7 | 8 | | 2 | 2
| | | | | | 1 | | | | | | | 4 | 1
| Consequence | | | | | | | | Consequence

Table 1: Risk matrices for the raw values; the left table corresponds to the raw values and the right table corresponds to the mitigated values.

1) Budget

The budget is a very important piece of the project that is likely to fail if nothing is done. A score of 5, 5 is necessary without mitigation.

If mitigated through fundraising events and donations through organizations such as TAMU ThinkTank and various TAMU departments, the budget will no longer be as likely to fail and thus will achieve a score of 3, 3.

2) Timeline

Following the timeline is necessary for the completion of the fabrication and testing phase of the ROV. Without following a structure for these phases, the team would not be able to achieve the functionality of the ROV for the product demonstration to qualify for the World’s competition. A score of 5,4 is necessary without mitigation.

In order to mitigate this risk, it is necessary to create an accurate and realistic Gantt chart that covers all phases that are necessary to make a functional ROV that could qualify for World’s. The Gantt chart must be followed at all times and buffers are necessary. If mitigated, the score of this risk will be 5,2.

3) Personnel Inexperience

A great majority of the members from Oceanus are new to underwater robotics, which makes mistakes and accidents very likely to occur. Without mitigation, the score for this risk would be 4,4.

Through the mentoring of people with greater technical skills, lots of documentation and research and communication, this risk can be mitigated to a score of 3,3.

4) Guideline Criteria

Due to the documentation that Oceanus has on the MATE ROV guidelines and other documents along with effective reinforced communication among peers, it is not very likely to deal with conflicts with the guideline criteria. For this reason, this risk has a score of a 5,2. If Oceanus fails to achieve an important criteria, the ROV won’t be able to compete in World’s.

By a constant process of validation and verification, where Oceanus makes sure that the ROV achieves the expected guidelines criteria, this risk will be mitigated to a 5,1.

5) Mechanical Risk

The ROV needs functional mechanical appendages to complete tasks, however failure of these components will not cause critical failure of the robot. A score of 3, 4 was given to this risk

Through constant testing, process of validation and verification, a spare part for most components, along with the assistance of mentors, this risk would be mitigated to a 2,3.

6) Electrical Risk

The electrical components are crucial to ROV functionality, any error in the electrical system during deployment would be catastrophic and costly to the ROV. For this risk the team has given a score of 5,4.

Through constant testing, process of validation and verification, a spare part for most components, along with the assistance of mentors, this risk would be mitigated to a 5,2.

7) Software Risk

Bugs are inevitable in complex systems, well constructed code would leave only edge case problems. The provided score of this risk is 4,3.

Through constant testing, process of validation and verification, proper organization, attention to detail and good practices the mitigated risk would be 2,2.

8) Integration Risk

Human error is introduced into the construction of the ROV, this could lead to issues with the physical construction of the ROV. This error would be both costly and delay the project. This risk has a score of 4,4.

Through constant testing, process of validation and verification, effective communication ,along with the assistance of mentors, this risk would be mitigated to a 3,2.

9) Structural Risk

The structure of the robot including chassis and electronics housing must remain intact to have a functioning ROV, however it is unlikely that critical failure will occur with standard construction practices. A score of 2,4 was given to this risk.

Through constant testing, process of validation and verification, a spare part for most components, along with the assistance of mentors, this risk would be mitigated to a 2,3.

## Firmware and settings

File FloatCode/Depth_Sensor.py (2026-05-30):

"""
MicroPython driver for the MS5837-30BA pressure/depth sensor over I2C.

Tested with the Blu-Sub Subsea M8 Depth Sensor (0-30 Bar / 0-300 m),
part BS-SSC-DPTHS-BLK-08A1, which packages the MS5837-30BA chip in a
waterproof M8 housing. The Blue Robotics Bar30 uses the same chip and
works with this driver unchanged.

Requires an I2C bus (3.3 V logic). Supply VIN at 5 V.
Provides read(), pressure(), temperature(), and depth() methods.

Example usage on Pico W:

    from machine import I2C, Pin
    import Depth_Sensor, time

    i2c = I2C(0, scl=Pin(1), sda=Pin(0), freq=400_000)
    sensor = Depth_Sensor.MS5837(i2c)

    while True:
        sensor.read()
        print(sensor.depth(), 'm', sensor.temperature(), 'C')
        time.sleep_ms(200)

"""

from micropython import const
import time


_MS5837_ADDR        = const(0x76)

_CMD_RESET          = const(0x1E)
_CMD_ADC_READ       = const(0x00)
_CMD_PROM_READ      = const(0xA0)   # base address; add 2*n for coefficient n (0..6)

# Convert D1 (pressure) - one command per OSR setting
_CMD_CONVERT_D1     = const(0x40)   # add 2*osr_index for higher OSR
# Convert D2 (temperature)
_CMD_CONVERT_D2     = const(0x50)   # add 2*osr_index for higher OSR

# OSR index: 0=256, 1=512, 2=1024, 3=2048, 4=4096, 5=8192
# Max conversion time per datasheet (ms), with 1 ms margin
_CONV_TIME_MS       = (1, 2, 3, 5, 10, 20)

# Fluid densities (kg/m^3) for converting pressure -> depth
DENSITY_FRESHWATER  = 997
DENSITY_SALTWATER   = 1029

_P_ATM_MBAR         = 1013.25       # standard atmospheric pressure
_G                  = 9.80665       # m/s^2


def _crc4(prom):
    # CRC4 check per MS5837-30BA datasheet. `prom` is a list of 7 uint16.
    n_rem = 0
    crc_read = prom[0]
    prom[0] = prom[0] & 0x0FFF      # strip CRC nibble from word 0
    prom.append(0)                  # virtual trailing byte
    for cnt in range(16):
        if cnt & 1:
            n_rem ^= prom[cnt >> 1] & 0x00FF
        else:
            n_rem ^= prom[cnt >> 1] >> 8
        for _ in range(8):
            if n_rem & 0x8000:
                n_rem = ((n_rem << 1) ^ 0x3000) & 0xFFFF
            else:
                n_rem = (n_rem << 1) & 0xFFFF
    prom.pop()
    prom[0] = crc_read              # restore for debugging
    return (n_rem >> 12) & 0x000F


class MS5837:
    def __init__(self, i2c, addr=_MS5837_ADDR, osr=5):
        self.i2c = i2c
        self.addr = addr
        # OSR index 0..5. 5 = 8192 samples, ~20 ms per conversion, best accuracy.
        # Drop to 3 or 4 if you need faster sampling for velocity calc.
        self.osr = osr

        self._buf2 = bytearray(2)
        self._buf3 = bytearray(3)
        self._C = [0] * 7           # PROM calibration coefficients C0..C6
        self._D1 = 0                # raw pressure ADC
        self._D2 = 0                # raw temperature ADC
        self._pressure_mbar = 0.0
        self._temperature_c = 0.0
        self.fluid_density = DENSITY_FRESHWATER

        self.init_sensor()

    def init_sensor(self):
        # Reset; datasheet requires >= 2.8 ms before next command
        try:
            self.i2c.writeto(self.addr, b"\x1e")
        except OSError:
            raise OSError("no MS5837 at I2C 0x%02x" % self.addr)
        time.sleep_ms(10)

        # Read 7 PROM coefficients (each 16-bit big-endian)
        for i in range(7):
            self.i2c.writeto(self.addr, bytes([_CMD_PROM_READ + (i * 2)]))
            self.i2c.readfrom_into(self.addr, self._buf2)
            self._C[i] = (self._buf2[0] << 8) | self._buf2[1]

        # Verify factory CRC
        crc_expected = (self._C[0] >> 12) & 0x000F
        crc_calc = _crc4(list(self._C))
        if crc_expected != crc_calc:
            raise OSError("MS5837 PROM CRC mismatch (got %d, want %d)"
                          % (crc_calc, crc_expected))

    def _convert(self, base_cmd):
        # Trigger ADC conversion, wait, then read 24-bit result
        self.i2c.writeto(self.addr, bytes([base_cmd + (self.osr * 2)]))
        time.sleep_ms(_CONV_TIME_MS[self.osr])
        self.i2c.writeto(self.addr, b"\x00")
        self.i2c.readfrom_into(self.addr, self._buf3)
        return (self._buf3[0] << 16) | (self._buf3[1] << 8) | self._buf3[2]

    def read(self):
        # Acquire raw D1 (pressure) and D2 (temperature)
        self._D1 = self._convert(_CMD_CONVERT_D1)
        self._D2 = self._convert(_CMD_CONVERT_D2)

        C = self._C

        # First-order compensation (MS5837-30BA datasheet)
        dT   = self._D2 - (C[5] << 8)
        TEMP = 2000 + ((dT * C[6]) >> 23)

        OFF  = (C[2] << 16) + ((C[4] * dT) >> 7)
        SENS = (C[1] << 15) + ((C[3] * dT) >> 8)

        # Second-order temperature compensation
        if TEMP < 2000:
            Ti    = (3 * (dT * dT)) >> 33
            OFFi  = (3 * ((TEMP - 2000) ** 2)) >> 1
            SENSi = (5 * ((TEMP - 2000) ** 2)) >> 3
            if TEMP < -1500:
                OFFi  += 7 * ((TEMP + 1500) ** 2)
                SENSi += 4 * ((TEMP + 1500) ** 2)
        else:
            Ti    = (2 * (dT * dT)) >> 37
            OFFi  = ((TEMP - 2000) ** 2) >> 4
            SENSi = 0

        OFF2  = OFF  - OFFi
        SENS2 = SENS - SENSi
        TEMP2 = TEMP - Ti

        # P is in 0.1 mbar units; TEMP2 is in 0.01 deg C
        P = (((self._D1 * SENS2) >> 21) - OFF2) >> 13

        self._pressure_mbar = P / 10.0
        self._temperature_c = TEMP2 / 100.0

    # -- accessors ----------------------------------------------------

    def pressure(self):
        # mbar (= hPa)
        return self._pressure_mbar

    def pressure_pa(self):
        return self._pressure_mbar * 100.0

    def temperature(self):
        # degrees Celsius
        return self._temperature_c

    def depth(self):
        # Depth in meters from gauge pressure: (P - P_atm) / (rho * g)
        return ((self._pressure_mbar - _P_ATM_MBAR) * 100.0
                / (self.fluid_density * _G))

    def altitude(self):
        # Above-sea-level altitude (m) when used in air, for sanity tests
        return (1 - (self._pressure_mbar / _P_ATM_MBAR) ** 0.190284) * 44307.69

    # -- config -------------------------------------------------------

    def set_fluid_density(self, density_kg_m3):
        # Pool water is between fresh (997) and salt (1029); set 1000 for
        # typical chlorinated pool water.
        self.fluid_density = density_kg_m3

    def set_osr(self, osr):
        # 0..5. Higher = more accurate, slower per read.
        if not 0 <= osr <= 5:
            raise ValueError("osr must be 0..5")
        self.osr = osr

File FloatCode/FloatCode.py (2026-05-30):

from machine import Pin, UART, I2C, SPI, ADC, PWM # This module allows us to set up the Pico W pins to specify I2C, UART, SPI, etc.
import time # We need this in order to keep track of timestamps during the mission
import os # Needed for reading/writing files to sd card
import vfs
import sdcard # Connects SD card to the Pico W using sdcard.py


### Activate Pico W pins ###
def setup_pins():
    uart0 = UART(0, baudrate=115200, tx=Pin(0), rx=Pin(1)) # Initialize UART0 pins for Ultrasonic Sensor
    i2c0 = I2C(0, sda=Pin(8), scl=Pin(9), freq=400000) # Initialize I2C pins for Pressure Sensor
    spi0 = SPI(0, baudrate=1000000, polarity=0, phase=0, sck=Pin(18), mosi=Pin(19), miso=Pin(16)) # Initialize SPI pins for SD Card Reader
    cs0 = Pin(17, Pin.OUT, value=1) # Initialize cs pin for SD Card Reader
    adc1 = ADC(27)
    pwm0 = PWM(Pin(14)) # PWM pin for peristaltic pump white (speed control) wire
    pwm0.freq(20000) # Keep 20kHz frequency for speed control, change duty cycle rate later
    pwm1 = PWM(Pin(15)) # PWM pin for peristaltic pump green (direction) wire

    return uart0, i2c0, spi0, cs0, adc1, pwm0, pwm1

def setup_sd_card(spi0, cs0):                            #Connnected  
    try:
        # 1. Initialize the SD card driver
        sd = sdcard.SDCard(spi0, cs0)
        # 2. Use the vfs module explicitly
        vfs_obj = vfs.VfsFat(sd)
        # 3. Mount it to the Pico's file system
        vfs.mount(vfs_obj, "/sd")
        print("SD Card successfully mounted at /sd")
        if "/sd" not in os.listdir("/"):
            print("SD mount failed")
    except Exception as e:
        print("SD Card Error:", e)

### Code for reading Pressure Sensor data and converting it to depth ###
def ms5837_init(i2c):
    i2c.writeto(0x76, bytes([0x1E]))
    time.sleep_ms(10)
    coeffs = []
    for k in range(6):
        i2c.writeto(0x76, bytes([0xA2 + k * 2]))
        raw = i2c.readfrom(0x76, 2)
        coeffs.append((raw[0] << 8) | raw[1])
    return coeffs

def _ms5837_read_raw(i2c, cmd):
    i2c.writeto(0x76, bytes([cmd]))
    time.sleep_ms(10)
    i2c.writeto(0x76, bytes([0x00]))
    d = i2c.readfrom(0x76, 3)
    return (d[0] << 16) | (d[1] << 8) | d[2]

def read_pressure_sensor(i2c, coeffs):
    C1, C2, C3, C4, C5, C6 = coeffs
    D1 = _ms5837_read_raw(i2c, 0x48)
    D2 = _ms5837_read_raw(i2c, 0x58)
    dT   = D2 - C5 * 256
    TEMP = 2000 + dT * C6 // 8388608
    OFF  = C2 * 65536 + (C4 * dT) // 128
    SENS = C1 * 32768 + (C3 * dT) // 256
    P    = (D1 * SENS // 2097152 - OFF) // 32768
    return P * 10, TEMP / 100.0
    
def scan_surface(uart, samples=5, ice_threshold_cm=30):
    """
    Sweep the ultrasonic sensor multiple times and vote on whether
    the surface is clear. Majority of readings must be obstacle-free
    to return True (clear). Fail-safe: if no valid readings are
    obtained at all, assumes blocked and returns False.
    """
    clear_count = 0
    valid_count = 0
    for _ in range(samples):
        dist = read_ultrasonic(uart)
        if dist is not None:
            valid_count += 1
            if dist > ice_threshold_cm:
                clear_count += 1
        time.sleep_ms(100)
    if valid_count == 0:
        print("[SCAN] No valid ultrasonic readings — assuming blocked")
        return False
    clear = clear_count > (valid_count // 2)
    print("[SCAN] {}/{} readings clear — surface {}".format(
        clear_count, valid_count, "CLEAR" if clear else "BLOCKED"))
    return clear

def calculate_depth(pressure_pa):                         # Pressure in Pascals
    surface_pressure = 101325 # Pascals at sea level
    density = 1000
    gravity = 9.81
    depth = (pressure_pa - surface_pressure) / (density * gravity)
    return max(0, depth) # Return 0 if negative


# Ultra sonic sensor                         
def read_ultrasonic(uart0):                                  # Ub
    uart0.read()  # flush stale buffer

    # Wait up to 500ms for 4 bytes
    t_start = time.ticks_ms()
    while uart0.any() < 4:
        if time.ticks_diff(time.ticks_ms(), t_start) > 500:
            return None  # timeout - nothing detected

    # Sync to header byte
    byte = uart0.read(1)
    if byte is None or byte[0] != 0xFF:
        return None

    # Read remaining 3 bytes
    rest = uart0.read(3)
    if rest is None or len(rest) < 3:
        return None

    high, low, checksum = rest[0], rest[1], rest[2]

    # Validate checksum
    if (0xFF + high + low) & 0xFF != checksum:
        print("Ultrasonic: checksum error")
        return None

    distance_cm = ((high << 8) | low) / 10.0

    # Sensor valid range: 5–600cm
    if not (50.0 <= distance_cm <= 600.0):  ###Modify when testing with real sensor###
        return None
    return distance_cm  # obstacle detected

### Code for using the sd card ###



#this is done in the main function
### Note: Use time module to keep track of time and write depth data to sd card every 5 seconds ###

### Code for using depth data to know when to actuate buoyancy engine ###


### Surfacing (end) phase ###
### Code for using Ultrasonic Sensor data to see when it is clear to surface ###

### Need to edit this function it isn't done yet


def actuate_buoyancy_engine(Speed_need, Direction):
    pwm =  Pin(14), freq=20000  # WHITE - speed control
    green = Pin(15, Pin.OUT)         # GREEN - direction

    def forward(Direction):
        green.init(Pin.OUT)
        green.value(0)

    def reverse(Direction):
        green.init(Pin.IN)

    def set_speed(Speed_need):
      if Speed_need < 11:
        pwm.duty_u16(0)
      else:
        pwm.duty_u16(int(Speed_need / 100 * 65535))
    def stop():
        set_speed(0)
    if Speed_need == 0:
        stop()


def buoyancy_down_on_ice(uart, ice_threshold_cm=30):
    """
    Detects ice above using the ultrasonic sensor and moves buoyancy engine down.
    """
    distance = read_ultrasonic(uart)
    if distance is not None and distance <= ice_threshold_cm:
        actuate_buoyancy_engine("down")
        return True
    return False
### Need to edit this function it isn't done yet
def determine_buoyancy_direction(depth, ice_detected, max_depth=10):
    """
    Decides whether the buoyancy engine should go up, down, or hold.
    """
    if ice_detected:
        return "down"
    elif depth >= max_depth:
        return "up"
    else:
        return None
    
def scan_surface(uart):
    return 0


"""
def scan_surface(uart, ice_threshold_cm=30):
    for i in range(5):
        raw = read_ultrasonic(uart)
        if raw:
            try:
                distance_cm = int(raw.decode().strip()[1:]) / 10.0
                return distance_cm <= ice_threshold_cm
            except:
                pass
    return True  # Fail-safe: assume ice
"""
def actuate_buoyancy_engine():
    print("Buoyancy engine activated")
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

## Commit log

2025-12-22 Create Cad files 2025-2026
2025-12-22 Rename PrototypeAssemblyChassis.SLDASM to ROV CAD files/PrototypeAssemblyChassis.SLDASM
    [PrototypeAssemblyChassis.SLDASM]
2025-12-22 Rename Float Assembly V1.SLDASM to ROV CAD files/Float Assembly V1.SLDASM
    [Float Assembly V1.SLDASM]
2026-01-05 Diamond Thruster Guard (Manufacturer's Shroud)
    This is a reupload of the previous file for security reasons.
2026-02-12 Add files via upload
    Updated some parts from the previous Diamond Dynamic Thruster Set-up, like changing screw hole sizes and fitting some things. Primarily, this is so then we can have an accurate enough thruster design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
2026-03-19 fixing ultrasonic sensor function to return the actual distance instead of a boolean
    [FloatCode.py]
2026-03-19 Update ultrasonic sensor function to return distance_cm instead of True/False and standardize failure cases to None
    [FloatCode.py]
2026-03-19 Update FloatCode.py-Add ADC reading to main loop for thermistor data
2026-03-19 Add SD card mount verification after initialization
2026-03-29 fix: main loop — adds coeffs, removes detect_ice crash, correct args to all functions
    [FloatCode.py]
2026-03-29 feat: add scan_surface() with multi-sample ultrasonic sweep
2026-05-19 Create assembly.md for ROV component guides
    Added a new document for assembly procedures.
2026-05-30 File upload
    [2025-2026 spec sheet.xlsx, 2026-2027 predictive budget.xlsx, Design Team Timeline Template.xlsx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]
2026-05-30 Uploaded EPS Files
    [Bill of Components.xlsx, Connector Trade Study.xlsx, EPS FLOAT Needs & Requirements.xlsx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]
2026-05-30 Uploaded EPS Files (for real this time)
    [Bill of Components.xlsx, Connector Trade Study.xlsx, EPS FLOAT Needs & Requirements.xlsx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]
2026-05-30 Add project files
    [1 x 2 brackets (cut 4) solid.DXF, 1 x 2 brackets (cut 4).DXF, 2024 Overall Scores.xlsx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]
2026-06-26 Add ArduSub SITL starter kit for 6-DoF simulation (GNC) (#12)
    * Add ArduSub SITL starter kit for 6-DoF simulation (GNC)
    Docker-based ArduSub SITL targeting the vectored_6dof (8-thruster, BlueROV2
    Heavy) frame so GNC can validate the custom 6-DoF frame config and control
    algorithms against the real firmware before hardware is ready. Matches the
    Navigator + Pi5 + BlueOS stack in GNC-ICD-01.
    Includes:
    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
    [vectored_6dof.parm]
2026-06-26 Relocate GNC software to root 01_Subteams/GNC; remove 26-27 (#14)
    Per team decision to use the top-level 01_Subteams (not the year folder):
    - Move the photogrammetry submodule and SITL-Simulation kit from
    25-26/01_Subteams/GNC/ to 01_Subteams/GNC/ (paths + .gitmodules updated,
    in-doc path references fixed).
    - Delete the 26-27 scaffold folder.
    [vectored_6dof.parm]
2026-06-26 Record final frame config decision: 8 thrusters, vectored_6dof (#16)
    Documents the team's final design (8 thrusters / FRAME_CONFIG=2) and resolves
    the 4-vs-8 conflict between the F&P trade study and the BOM/ICD wiring. Notes
    the one remaining CAD check (horizontal thruster angle).
2026-06-26 Add CSV telemetry logger for SITL/hardware data capture (#17)
    Records depth, attitude, NED position, velocities, battery, and all 8 thruster
    outputs to CSV at a fixed rate — for test-report plots and the GNC performance
    metrics. Same MAVLink path works on SITL now and the Navigator later.
    [log_telemetry.py]
2026-06-26 Add telemetry dashboard generator for presenting test results (#18)
    plot_telemetry.py renders a logged CSV into one shareable PNG dashboard:
    top-down path, depth profile, attitude, thruster outputs (horizontal vs
    vertical), power draw, and speed. Lets GNC present sim/hardware testing as a
    figure for reports and slides instead of raw numbers. Adds matplotlib/numpy to
    requirements and a capture->plot workflow to the README.
2026-06-26 Patch SITL physics with Team Oceanus vehicle model (#19)
    Replaces ArduPilot's stock BlueROV2 SITL submarine model with Oceanus' values
    (mass 22kg target, ~0.6x0.5x0.35m, 8x T200 @ 51.48N, neutral buoyancy) via
    apply_oceanus_model.sh, applied at image-build time. Each value is tagged with
    source/confidence in OCEANUS-VEHICLE-MODEL.md.
    Note: repo has no measured ROV mass/dimensions (spec sheet is blank) — values
    are design targets + component data + estimates, meant to be updated once the
    ROV is built and weighed. Firmware/control behavior is unaffected.
2026-06-26 Add sample SITL runs (baseline vs Oceanus model dashboards + CSVs) (#20)
    Example telemetry from the same maneuver under the stock BlueROV2 model and the
    Oceanus 22kg model, with dashboard PNGs and raw CSVs, documenting the heavier
    vehicle's shallower dive on identical input.
    [bluerov2-baseline_telemetry.csv, oceanus-22kg_telemetry.csv]
2026-06-26 Correct thruster to Diamond Dynamics TD1.2 (24.5N, not T200) (#21)
    The actual thrusters are Diamond Dynamics TD1.2 (~2.5 kgf max each), confirmed
    by the user and the Technical Report ('1.2-2.5 kg thrust per unit') — the BOM's
    T200 line was a placeholder. Updates the SITL vehicle model thrust 51.48 -> 24.5
    N, the model + frame-config docs, and regenerates the Oceanus sample run
    (same command now dives ~3.5 m vs ~5.8 m baseline; top speed ~0.7 vs 1.2 m/s).
    [oceanus-22kg_telemetry.csv, oceanus-td12_telemetry.csv]
2026-06-26 Add water-current testing for ConOps current compensation (#22)
    Stock ArduSub SITL never applies wind/current to the submarine drag, so the
    default sim is still water. apply_current_model.sh patches SIM_Submarine.cpp so
    SIM_WIND_SPD/DIR act as a horizontal water current (drag on velocity relative to
    the moving water); baked into the image via the Dockerfile.
    Adds scripts/inject_current.py (set/clear/demo current live) and a current-drift
    sample run: holding depth, a 0.6 m/s current drifts the ROV ~14 m east — the
    disturbance the GNC current-compensation control must counter. Validated: ROV
    drifts at the current speed (0.5 m/s -> 0.49 m/s, 1.0 -> 0.99).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
    [current-drift_telemetry.csv]
2026-06-27 Add PID station-keeping (current compensation) (#23)
    station_keeping.py holds horizontal position against a water current: PID on NED
    position error -> forward/lateral thrust in DEPTH_HOLD (autopilot holds depth).
    Implements the ConOps current-compensation / drift task, bridging the pseudocode
    position-tracking to working control code.
    Validated: holds to ~0.01 m steady-state vs a 0.4 m/s current (integral term
    removes the P/PD droop). Sample current-compensation run: ~3.9 m drift during a
    no-control phase, recovered to within ~0.2 m and held.
    [current-compensation_telemetry.csv]
2026-06-27 Tune station-keeping gains + add variable-current sample (#24)
    Bank the tuned PID gains (Kp=440 Kd=230 Ki=210, limit 400) as defaults — on a
    fixed random-current sequence they roughly halve the hold error vs the original
    (mean 0.22->0.12 m, max 0.47->0.31 m).
    Adds a variable-current sample: station-keeping vs a random current that changes
    every ~3-4 s (13 changes), with the telemetry dashboard, a disturbance-vs-error
    response chart, and both CSVs. Demonstrates the controller is stable against a
    non-constant disturbance, not just a fixed one.
    [variable-current_current.csv, variable-current_telemetry.csv]
2026-06-27 Add servo control architecture + test (Goal 2) (#25)
    servo_control.py drives the manipulator servos on channels 14-16 (GNC-ICD-01)
    via MAV_CMD_DO_SET_SERVO (those channels default to FUNCTION=0, so the GCS can
    command them directly). servo_test.py measures command-path latency + precision
    and writes a CSV, chart, and the Goal 2 test report.
    SITL results: command latency ~10 ms mean (p95 ~18 ms), 0 us command error. Adds
    the servo-control_* sample (report + chart + data). SITL validates the
    software/comms path; mechanical travel + physical precision are bench tests.
    [servo-control.csv]
2026-06-28 Flesh out team README — overview, subteams, repo layout (#32)
